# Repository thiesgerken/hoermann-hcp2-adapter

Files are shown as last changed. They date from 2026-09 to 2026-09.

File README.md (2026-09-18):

<div align="center">

# Hörmann HCP2 Adapter

**An open carrier PCB and 3D-printable enclosure for connecting an ESP32-C3 to a Hörmann Series 4 garage door opener.**






</div>

<p align="center">
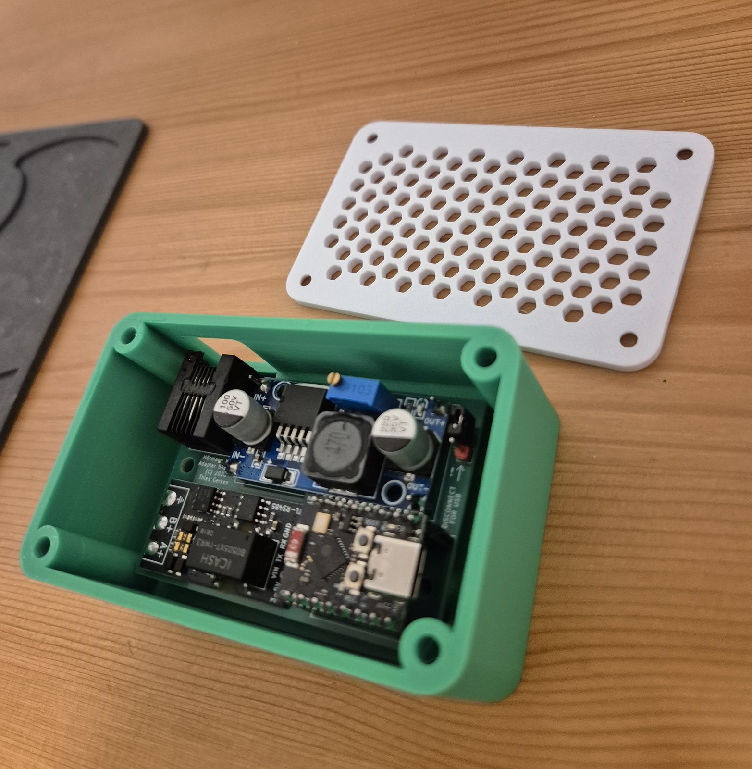
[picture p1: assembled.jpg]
The assembled adapter in its printed tray, with the ventilated lid beside it
  
</p>

<table>
<tr>
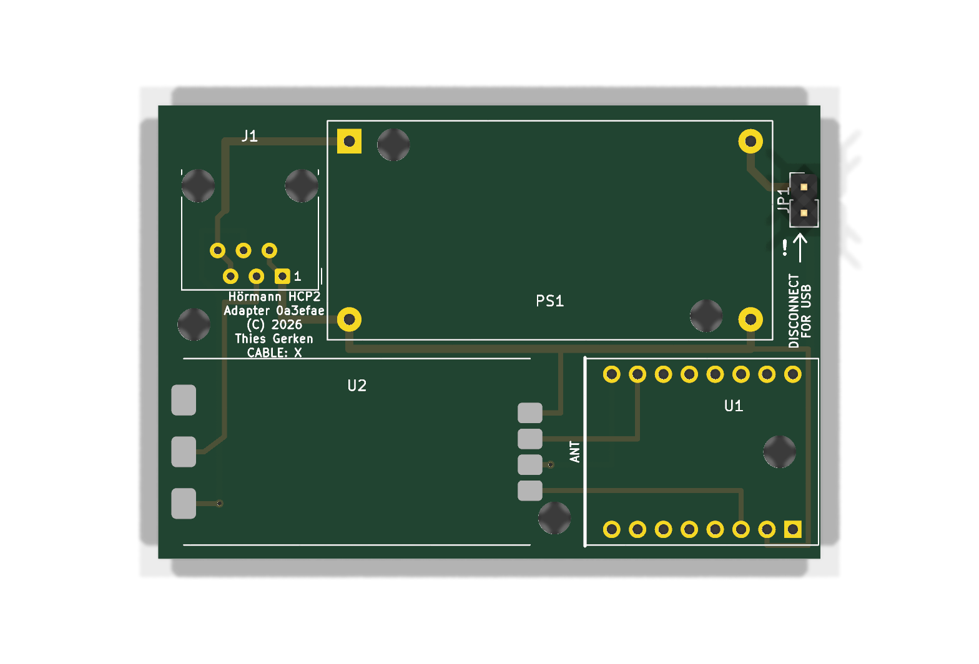
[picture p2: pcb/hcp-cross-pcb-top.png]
Top view of the Hörmann HCP2 adapter PCB
<td width="34%" align="center"><br><strong>65 × 44.5 mm carrier PCB</strong></td>
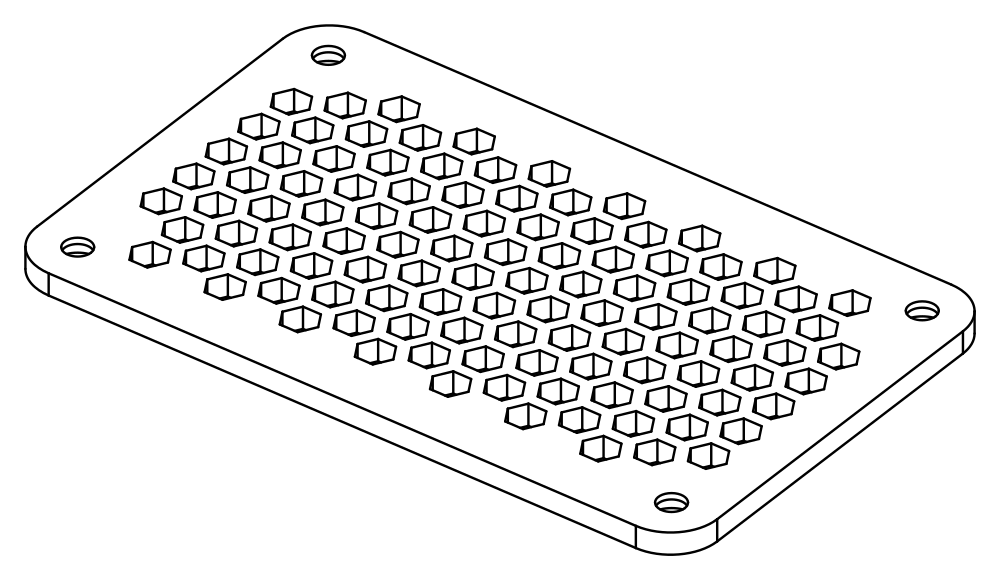
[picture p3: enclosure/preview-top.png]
Enclosure lid CAD preview
<td width="33%" align="center"><br><strong>Ventilated lid</strong></td>
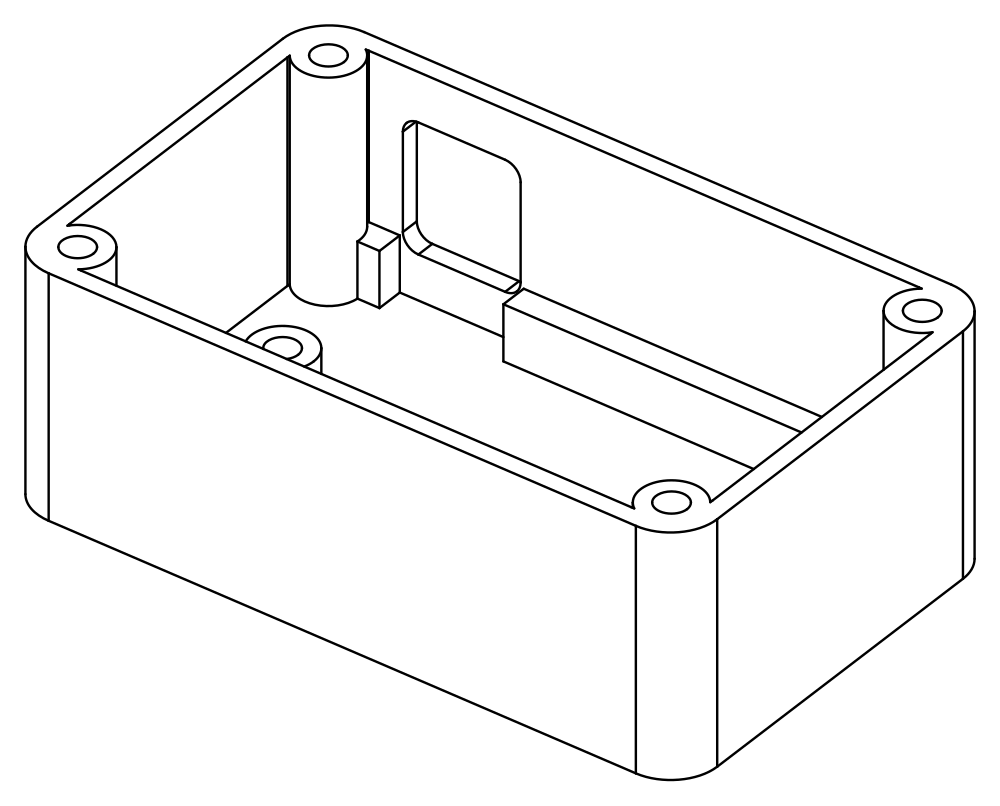
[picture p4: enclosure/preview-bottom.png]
Enclosure tray CAD preview
<td width="33%" align="center"><br><strong>Fitted electronics tray</strong></td>
</tr>
</table>

> [!CAUTION]
> Verify the pinout of your own opener and every conductor of your cable before connecting anything. See [Variants](#variants).
>
> Use this project entirely at your own risk. I am not responsible for any damage, injury, loss, or other consequence resulting from its use in any way. This independent project is not affiliated with, endorsed by, or sponsored by Hörmann.

This is the documentation repository for how I built my adapter around the [ESPHome Hörmann HCP component](https://esphome.io/components/cover/hoermann_hcp/). It may be useful for other people building one as well.

It includes:

- 🧩 a fully routed two-layer KiCad carrier PCB with project-specific footprints
- ⚙️ reproducible Python generators for the schematic, PCB, manufacturing outputs, and renders
- 📦 a compact, parametric build123d enclosure matched directly to the PCB geometry
- 🔌 a ready-to-flash ESPHome configuration with Wi-Fi provisioning
- 🖨️ printable STL files and 3MF assembly previews
- 📚 documented mechanical, electrical, and sourcing decisions

## BOM

### Electronics

| Qty. | Ref. | Component | Notes |
|---:|---|---|---|
| 1 | PCB | Carrier PCB | Two-layer, 65 × 44.5 mm; fabrication files are in [`pcb/`](pcb/) |
| 1 | U1 | [ESP32-C3 Super Mini](reference/docs/purchased-modules.md#esp32-c3-super-mini) | Socketed; runs ESPHome |
| 1 | PS1 | [LM2596 HW-411 buck converter](reference/docs/purchased-modules.md#lm2596-buck-converter-module) | Adjustable; set and verify 5.0 V before connecting U1 |
| 1 | U2 | [Isolated TTL-to-RS485 module](reference/docs/purchased-modules.md#isolated-ttl-to-rs485-module) | 3.3 V/5 V, automatic direction control, integrated 120 Ω termination |
| 1 | J1 | [Unshielded right-angle 6P6C jack](reference/docs/connector-rj12.md) | AliExpress item `1005003078110991`, option `6P6C` |
| 1 | JP1 | 1×2, 2.54 mm pin header and jumper shunt | Disconnects `BUS_PWR` before USB is connected |
| 2 | U1 sockets | 1×8, 2.54 mm socket headers | Keep U1 removable and provide clearance above H4 |
| 1 | W1 | [6P6C cable](reference/docs/purchased-modules.md#6p6c-cable) | Reversed for the `cross` board, straight-through for `straight`. See [Variants](#variants). Verify all six conductors before use |

### Enclosure

| Qty. | Component | Notes |
|---:|---|---|
| 1 | Printed `bottom.stl` | Tray with PCB supports and 6P6C opening |
| 1 | Printed `top.stl` | Ventilated lid |
| 7 | Ruthex M3 heat-set inserts, 5.7 mm long, Ø4.0 mm hole | Four for the lid columns and three for the PCB bosses |
| 4 | M3 × 6 socket cap screws | Lid. Anything longer than 7.5 mm bottoms out in the blind hole |
| 3 | M3 × 6 socket cap screws | PCB. Full thread engagement would need 7.3 mm, and 4.4 mm is ample for M3 |

The LM2596 is not galvanically isolated. The complete adapter therefore shares the HCP supply ground even though the RS485 signal path is isolated. Full galvanic isolation would require an isolated DC/DC converter.

## 🧩 PCB

The [`pcb/`](pcb/) directory is the electrical source of truth. It contains the shared net model, schematic and layout generators, custom footprints, generated KiCad projects, renders, ERC and DRC reports, and fabrication files.

| Property | Value |
|---|---|
| Board | 2 layers, 65 × 44.5 mm |
| Routing | 0.5 mm signals, 0.8 mm power, two vias, three on the straight variant |
| Input | Hörmann HCP2 through a 6P6C jack |
| Controller | Socketed ESP32-C3 Super Mini |
| Power | LM2596 module, approximately 25 V to 5 V |
| Bus interface | Isolated automatic-direction TTL-to-RS485 module |
| Mounting | Three M3 board holes plus one supported corner |

### Variants

Two boards are generated from the same sources. They are identical except for how the six
contacts of J1 map onto the nets, and each one says on its silkscreen which cable it wants.

| Variant | Silkscreen | Cable | J1 contacts |
|---|---|---|---|
| `cross` | `CABLE: X` | Reversed (rollover) | 1, 2 GND · 3 B- · 4 A+ · 5, 6 +25 V |
| `straight` | `CABLE: II` | Straight-through 1:1 | 1, 2 +25 V · 3 A+ · 4 B- · 5, 6 GND |

`cross` follows the pinout in the ESPHome documentation and is the board built and tested
here. The openers measured for this project are mirrored against that pinout, which is why
it needs a reversed cable. `straight` exists for anyone who would rather buy an ordinary
1:1 cable, and for openers that turn out to match it directly.

Measure your own opener before ordering either board. Getting this wrong puts +25 V on the
adapter's ground.

### Layout

| Reference | Part and placement |
|---|---|
| J1 | Amphenol 54601-compatible right-angle 6P6C jack, flush with the top board edge |
| PS1 | 43.4 × 21.2 mm LM2596 HW-411 module, input side toward J1 |
| U2 | 34 × 18 mm isolated RS485 module on castellated pads |
| U1 | ESP32-C3 Super Mini, USB-C flush with the right edge and antenna facing U2 |
| JP1 | `BUS_PWR` disconnect jumper for safe USB use |
| H1, H3, H4 | 3.2 mm M3 mounting holes aligned with the enclosure bosses |

### Generate the design

KiCad must be installed and `kicad-cli` must be available.

```sh
for variant in cross straight; do
  uv run python pcb/schematic.py $variant
  uv run python pcb/pcb.py $variant
done
```

The generators write editable KiCad files directly to [`pcb/`](pcb/), run ERC and DRC, render the schematic and both board sides, and package Gerber and Excellon data. Omitting the argument builds `cross`.

Useful outputs, per variant:

| | Reversed cable | Straight cable |
|---|---|---|
| Editable schematic | [`hcp-cross.kicad_sch`](pcb/hcp-cross.kicad_sch) | [`hcp-straight.kicad_sch`](pcb/hcp-straight.kicad_sch) |
| Schematic PDF | [`hcp-cross-schematic.pdf`](pcb/hcp-cross-schematic.pdf) | [`hcp-straight-schematic.pdf`](pcb/hcp-straight-schematic.pdf) |
| Editable PCB | [`hcp-cross.kicad_pcb`](pcb/hcp-cross.kicad_pcb) | [`hcp-straight.kicad_pcb`](pcb/hcp-straight.kicad_pcb) |
| Layer PDF | [`hcp-cross-pcb.pdf`](pcb/hcp-cross-pcb.pdf) | [`hcp-straight-pcb.pdf`](pcb/hcp-straight-pcb.pdf) |
| Gerber and drill archive | [`hcp-cross-gerbers.zip`](pcb/hcp-cross-gerbers.zip) | [`hcp-straight-gerbers.zip`](pcb/hcp-straight-gerbers.zip) |

The title blocks include the short Git hash of `HEAD`. For release artifacts, commit the sources first, regenerate all four designs, then commit the generated outputs.

## 📦 Enclosure

The [`enclosure/`](enclosure/) directory contains a two-part indoor enclosure generated with [build123d](https://build123d.readthedocs.io/):

- `bottom.stl`: tray with three PCB bosses, a support rail, corner columns, and the 6P6C opening
- `top.stl`: screw-fastened lid with a hexagonal ventilation pattern
- `preview.stl`: open assembly for any STL viewer
- `preview.3mf`: colored assembly with lid and internal hardware

The outer size is **87.8 × 54.3 × 34.0 mm**. Four M3 screws secure the lid into Ruthex threaded inserts. The enclosure is intended for an indoor garage wall and is not waterproof.

PCB dimensions, hole positions, and module placement are imported from [`pcb/pcb.py`](pcb/pcb.py) and the KiCad footprints. Only vertical dimensions and simplified component bodies are maintained separately.

```sh
uv sync
uv run python enclosure/case.py
uv run python enclosure/case.py --show
uv run python enclosure/case.py --png
uv run python enclosure/test_case.py
```

See the [enclosure documentation](enclosure/README.md) for print orientation, clearances, viewer setup, and the mechanical decisions behind the model.

## Assembly notes

Before soldering PS1 onto the carrier board:

1. Power the loose LM2596 module from approximately 25 V with no ESP32 connected.
2. Adjust its output to 5.0 V using the `103` trimmer.
3. Check startup and shutdown behavior under load. The output must not overshoot beyond 5.5 V.
4. Solder PS1 only after those checks pass. Keep `BUS_PWR` open until the remaining board is assembled.

U1 plugs into two 1×8 socket headers. Install the headers, fasten the PCB inside the enclosure, then insert the ESP32. Never connect USB while `BUS_PWR` links the externally supplied 5 V rail.

## HCP2 interface

The ESPHome documentation specifies this pinout for supported Hörmann Series 4 openers:

| Pin | Signal |
|---:|---|
| 1 | GND |
| 2 | GND |
| 3 | B- |
| 4 | A+ |
| 5 | +25 V |
| 6 | +25 V |

The opener's own jack is mirrored against that table: on the ProMatic 4 measured here,
+25 V sits on contacts 1 and 2. The `cross` board follows the table and therefore needs a
**reversed (rollover) cable**, the kind whose two plugs show opposite conductor order when
held identically. The `straight` board mirrors J1 instead and takes a plain 1:1 cable. See
[Variants](#variants).

Measure your opener and every conductor of your cable before the first connection. Pairing
the wrong cable with either board feeds +25 V into the adapter's ground. Doing that here
survived only because the opener limits accessory current to 350 mA.

UART settings: **57600 baud, 8 data bits, even parity, 1 stop bit**. ESPHome participates as a Modbus server. The configuration is in [`esphome/`](esphome/README.md) and uses `GPIO20` for TX and `GPIO21` for RX. That looks reversed next to the net
names on the board, and it is not: U2's TTL pads carry the module's own pin names, so
its `TX` pad drives the ESP32 rather than being driven by it.

## Troubleshooting

The bus offers a hostile debugging environment: it carries power only during a bus scan,
and the opener cuts it again within seconds when the adapter fails to register. That is
too short to read a log. These checks all work on the bench instead, with the board on a
25 V supply and the bus disconnected.

**Does the transmitter work?** Send continuously and measure the DC average, which a plain
multimeter resolves. A temporary `interval` writing 128 zero bytes every 30 ms keeps the
line low about 80 % of the time. Measure between U2's A and B pads:

| A against B | Meaning |
|---|---|
| about 185 mV, unchanged while sending | The driver never switches on. Check the pin roles first |
| moves to roughly 1.6 V while sending | Transmit path is good |
| exactly 0.000 V | The isolated side is not running. The module is dead or unpowered |

The 185 mV is the module's fail-safe bias, so seeing it at all proves the isolated side
has power.

**Does the receiver work?** With the bus disconnected, GPIO21 must sit at a steady 3.3 V.
That is U2's receiver output holding the UART idle level. A wandering level below 0.5 V
means the receiver output is not driving, or the castellated joint is cold.

**Is anything arriving from the bus?** Count bytes instead of logging them. A `uart:`
`debug:` block with a custom `sequence` replaces the default hex dump, so it costs no log
traffic, and a global written to flash with `global_preferences->sync()` survives the
supply being cut. Drive the onboard LED from it and the answer is readable in the garage
without a host attached. Set `dummy_receiver: true` while measuring so the counter does
not depend on Modbus draining the UART, and back to `false` for normal operation.

**Verify the counter before trusting it.** Point the UART at two free neighbouring pins,
GPIO4 and GPIO3, and bridge them. Crosstalk from the transmitting pin is enough to make
the counter run even without the bridge.

## ⚠️ Safety and operating constraints

- Scope is limited to supported Hörmann Series 4 HCP2 devices.
- Disconnect mains power and any emergency battery before installation.
- HCP2 accessories must not be connected or removed while powered.
- Interrupted communication or an ESPHome restart can temporarily block the opener. Power-cycling the opener clears this condition.
- The bus provides approximately 25 V only during a bus scan. The adapter must boot and respond in time.
- Verify the actual jack contact order and every conductor of the cable before first connection, and check that the cable matches the variant printed on the board.
- The selected RS485 module reportedly includes 120 Ω termination. Measure A-to-B resistance with power removed before use. Do not fit a second termination.
- Hörmann specifies a combined 350 mA accessory limit. Measure adapter startup and operating current.

## Repository map

```text
assembled.jpg        Photo of the assembled adapter
LICENSE              MIT, except for the archived third-party material
pcb/                 PCB, schematic, footprints, and fabrication outputs
enclosure/           Parametric enclosure source and printable files
esphome/             ESPHome configuration for the ESP32-C3
reference/docs/      Design records, component notes, and source analysis
reference/           Archived vendor pages, manuals, and datasheets
TODO.md              Open checks, currently none
```

Reference material is intentionally separated from the project deliverables. Start with [`pcb/`](pcb/), [`enclosure/`](enclosure/), and [`esphome/`](esphome/); use [`reference/docs/`](reference/docs/) when a design decision or source needs review.

## License

[MIT](LICENSE), covering the PCB, the enclosure, the generators, the ESPHome
configuration, and the documentation.

[`reference/`](reference/README.md) is excluded. It archives manuals, datasheets, and
vendor listings that belong to their respective owners, with the exception of
[`reference/docs/`](reference/docs/), which is mine and follows the license above.

## Documentation

- [Enclosure design](enclosure/README.md)
- [Firmware](esphome/README.md)
- [Open checks](TODO.md)
- [Components and sourcing status](reference/docs/components.md)
- [Purchased modules](reference/docs/purchased-modules.md)
- [Selected 6P6C jack](reference/docs/connector-rj12.md)
- [Hörmann manual analysis](reference/docs/hoermann-manuals.md)
- [Sources and references](reference/docs/references.md)
- [Decision log](reference/docs/decisions.md)
- [Local vendor archive](reference/README.md)

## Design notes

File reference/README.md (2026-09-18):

# Local source archive

Vendor pages were retrieved on 2026-09-05.

## Copyright

Everything in this directory except [`docs/`](docs/) is third-party material, archived so
that the design decisions in this repository stay verifiable. None of it is my work, none
of it is covered by the repository's MIT license, and no permission to redistribute it is
granted or implied. Rights remain with the respective owners.

| Material | Rights holder |
|---|---|
| [`manuals/`](manuals/) | Hörmann KG. ProMatic 4 opener and accessory documentation. |
| `datasheets/lm2596-ti-snvs124g.pdf` | Texas Instruments |
| `datasheets/esp32-c3-espressif-v2.4.pdf` | Espressif Systems |
| `datasheets/esp32-c3-supermini-community.pdf` | Unattributed vendor document circulating with the board |
| `aliexpress-*/` | The respective sellers and manufacturers. Listing text and images. |
| `esphome-hoermann-hcp-wiring.svg` | The ESPHome project. Taken from its documentation, which is licensed CC BY-NC-SA 4.0. |

[`docs/`](docs/) holds my own design records, component notes, and source analysis, and
follows the repository's [MIT license](../LICENSE).

If you hold rights to any of this material and want it removed, get in touch and I will
take it down.

## Archive contents

| Item | Archived content | Details |
|---|---|---|
| 6P6C cable | Product description, rendered and raw pages, gallery | [`aliexpress-1005005913976427/README.md`](aliexpress-1005005913976427/README.md) |
| 120 Ω resistor | Product description, rendered and raw pages, gallery | [`aliexpress-1005007375826162/README.md`](aliexpress-1005007375826162/README.md) |
| Isolated TTL-to-RS485 module | Product description, rendered and raw pages, gallery | [`aliexpress-1005010178764203/README.md`](aliexpress-1005010178764203/README.md) |
| LM2596 module | Product description, rendered and raw pages, gallery | [`aliexpress-1005006362601789/README.md`](aliexpress-1005006362601789/README.md) |
| ESP32-C3 Super Mini | Product description, rendered and raw pages, gallery | [`aliexpress-1005005967641936/README.md`](aliexpress-1005005967641936/README.md) |
| Selected 6P6C jack | Product description, product pages, gallery, labeled SKU images | [`aliexpress-1005003078110991/README.md`](aliexpress-1005003078110991/README.md) |

`product-description.txt` contains readable text extracted from the rendered product page. `product-page-rendered.html` preserves the generated DOM at retrieval time. `product-page-raw.html`, or `product-page.html` where present, is the raw server response. Gallery images may show different physical variants when a listing offers multiple options.

Vendor claims are not manufacturer datasheets. Footprints, pinouts, and electrical limits must be based on measurements of the delivered sample or applicable manufacturer documentation.

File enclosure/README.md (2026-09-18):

# 📦 Parametric enclosure

A compact 3D-printable enclosure for the carrier PCB in [`../pcb/`](../pcb/).
The model is fully parametric Python built with [build123d](https://build123d.readthedocs.io).

<table>
<tr>
<td width="50%" align="center">Enclosure lid CAD preview<br><strong>Ventilated screw-fastened lid</strong></td>
<td width="50%" align="center">Enclosure tray CAD preview<br><strong>Tray with PCB supports and connector opening</strong></td>
</tr>
</table>

The enclosure has two parts: `bottom.stl`, the tray, and `top.stl`, the lid with a hexagonal ventilation pattern. Four M3 screws fasten the lid into Ruthex threaded inserts in the corner columns. The PCB sits on three bosses below H1, H3, and H4, while a rail supports the remaining corner near the jack. There is no gasket because the enclosure is not waterproof.

**Outer size:** 87.8 × 54.3 × 34.0 mm  
**Inner size:** 83 × 49.5 × 28.8 mm

`case.py` reads the board dimensions, hole pattern, and module locations directly from [`../pcb/pcb.py`](../pcb/pcb.py) and the footprints in `../pcb/HCP.pretty/`. Only component heights and simplified module bodies are maintained manually.

> [!NOTE]
> The module heights in the parameter block come from vendor data. They were checked
> against the assembled board and the printed tray and needed no correction, but they stay
> worth a look if a module is sourced elsewhere.

## Workflow

```sh
uv sync                              # install build123d and ocp-vscode once
uv run python enclosure/case.py       # write the STL and 3MF files
uv run python enclosure/case.py --show
uv run python enclosure/case.py --png
uv run python enclosure/test_case.py  # verify clearances and fit constraints
```

Every run prints the bounding box and volume of both parts. Outputs are written beside the script:

- `bottom.stl` and `top.stl`: print-ready parts
- `preview.stl`: tray, PCB, modules, and plug for generic STL viewers
- `preview.3mf`: named and colored assembly including the lid, with transparency where supported

### Live viewer

Start the viewer in a separate terminal and leave it running:

```sh
uv run python -m ocp_vscode
```

Open <http://127.0.0.1:3939/viewer>, or use the OCP CAD Viewer extension in VS Code. Each `--show` invocation replaces the model while preserving the camera position. Hide the lid in the object tree to inspect the PCB, module envelopes, solder joints, mounting hardware, and inserted 6P6C plug.

The `--png` option renders isometric line drawings without hidden edges. It requires `rsvg-convert`, available on macOS through `brew install librsvg`.

## Layout

Top view with +Y upward. The PCB orientation matches the KiCad render. J1 faces the +Y wall and the U1 USB-C connector faces +X without an external opening.

```text
          ╡ 6P6C ╞
   ┌─────────────────────────────┐
   │ o                         o │   o = corner column with M3 insert
   │   [J1] [   PS1 LM2596   ]JP1│
   │   [ U2 RS485 ] [U1 ESP32-C3]│
   │ o                         o │
   └─────────────────────────────┘
```

## Dimensions

| Feature | Dimension or constraint |
|---|---|
| Walls and floor | 2.4 mm, equal to six 0.4 mm extrusion widths |
| Lid | 2.8 mm |
| PCB | 65 × 44.5 × 1.6 mm, Ø3.2 mm holes from `pcb.py` |
| PCB bosses | 3 × Ø8 × 7.2 mm below H1, H3, H4; Ø4.0 × 6.7 mm blind holes for Ruthex M3 inserts; 1 mm foot fillet |
| Support rail | Along the +Y wall between columns, interrupted at the jack; 3.5 mm deep and 1.5 mm below the PCB edge |
| PCB clearance | 9 mm at ±X, 2 mm toward the jack at +Y, 3 mm at -Y |
| Height above PCB | 16 mm reserved, plus 4 mm lid clearance |
| Jack J1 | 13.2 × 18 mm from the footprint, 11.65 mm high per vendor drawing, latch toward PCB |
| Plug opening | 15.2 × 16.65 mm, 2 mm corner radius, from 3 mm below to 2 mm above the jack |
| Ventilation | 4 mm hexagons across flats, 1.6 mm webs, 2 mm margin from wall rim and screw recesses |
| Lid screws | 4 × M3, Ø3.4 mm clearance, Ø6 × 2 mm counterbore |
| Fasteners | 7 × Ruthex M3 inserts, 5.7 mm long; 7 × M3 × 6 socket cap screws |

## Mechanical decisions

### 9 mm side clearance

The clearance accommodates the corner columns. Components occupy all four PCB corners, so each column must sit beside the board instead of above it. A narrower enclosure would require moving the lid screws or reducing `column_reach` through a smaller `corner_radius`.

### 2.4 mm walls

This small indoor enclosure does not need the 3.2 mm walls used for larger sealed outdoor boxes. Commercial small enclosures commonly use 2 to 2.5 mm walls. The columns overlap 2 mm into the wall and remain within the outer profile.

### One external opening

USB-C remains inside. Remove the lid for flashing and disconnect `BUS_PWR` before connecting USB. JP1 is internal as well. An external USB cutout can be added in `build_bottom()` if operational access becomes necessary.

### Three bosses and one support rail

The PCB has three suitable mounting holes. There is no room for an Ø8 mm boss near the PS1 pads in the fourth corner, so that corner rests on the +Y support rail. Boss faces must remain clear of solder joints. `test_case.py` derives the required boss clearance from every footprint pad using boss radius, pad radius, and a 0.25 mm margin.

### Opening extends below the PCB

The jack latch faces the PCB. The plug lever therefore passes below the plug body and needs clearance beneath the jack face. The support rail is interrupted at the opening, while nearby boss H1 supports the PCB edge.

### 7.2 mm bosses

The Ruthex insert length determines boss height, not the 2 mm solder-joint clearance. The blind hole must remain inside the boss because the floor is too thin to receive the insert.

### 1 mm boss fillet

The bosses sit close to walls, the support rail, and corner columns. A 1 mm fillet avoids collisions. `test_case.py` checks every fillet envelope.

### Lid-only ventilation

Warm air rises, while solid tray walls retain stiffness. The hex grid is clipped to the internal opening so the lid bears continuously on the wall rim and leaves sufficient material around screw recesses.

## Print settings

Wall and web thicknesses are multiples of the 0.4 mm extrusion width and every Z dimension is a multiple of 0.2 mm, so a slicer on that grid fills them with whole extrusions instead of infill.

| Setting | Value | Reason |
|---|---|---|
| Layer height | 0.2 mm | no feature needs finer resolution |
| Wall loops | 3 | 1.2 mm per side fills the 2.4 mm wall and the 2.0 mm ring around each insert completely |
| Extrusion width | 0.4 mm | profiles using 0.42 or 0.45 mm turn the 0.4 mm grid into gap fill |
| Top / bottom layers | 5 / 4 | the 2.4 mm floor is twelve layers |
| Infill | 20 to 25 %, gyroid | carries only the floor and the column cores |
| Supports | optional, tray only | the 15.2 mm plug opening bridges; support there breaks away easily |
| Brim | lid only | a 2.8 mm perforated plate lifts at the corners |
| Hole compensation | none | inserts want tight blind holes, and M3 passes a Ø3.4 hole printed undersize |

PETG is preferred over PLA. It holds screw torque at the threaded inserts better and tolerates a warm garage, although either material works indoors.

The tray prints floor down as exported. Rotate the lid 180° so the screw counterbores face up, which removes the only overhang in that part.

## Before the final print

- Measure the installed heights of the LM2596 including capacitors, the socketed ESP32 including USB-C, and jack J1. Compare the largest value plus clearance with `parts_height`.
- Verify the physical jack height against the 11.65 mm drawing value in `jack_height`.
- Trial-fit a 6P6C plug. The 18 mm deep jack leaves little plug body outside the wall. Confirm that the latch remains reachable through the opening extension below the jack.
- Check the unsupported upper-right PCB corner for play after assembly. It rests only on the support rail.

## Files

```text
case.py        Parametric model and user-facing dimensions
outputs.py     STL, 3MF, PNG, and live-view exports
test_case.py   Clearance and simplified assembly checks
bottom.stl     Print-ready tray
top.stl        Print-ready lid, exterior face down; flip it for printing
preview.stl    Open assembly for viewing only
preview.3mf    Colored complete assembly for viewing only
```

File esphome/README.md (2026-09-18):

# Firmware

ESPHome configuration for the adapter, built around the
[Hörmann HCP component](https://esphome.io/components/cover/hoermann_hcp/).

[`hcp.yaml`](hcp.yaml) exposes the door as a cover, the opener light, the vent and
half-open buttons, and a diagnostic sensor for the bus connection. Wi-Fi credentials,
the API key, and the OTA password live in `secrets.yaml`, which is not committed.

## Setup

```sh
cp esphome/secrets.yaml.example esphome/secrets.yaml   # then fill it in
uvx esphome run esphome/hcp.yaml
```

The first flash needs USB. Hold `BOOT`, press and release `RST`, then release `BOOT` to
enter download mode. Disconnect `JP1` while USB is plugged in, because the LM2596 and USB
would otherwise drive the 5 V rail at the same time.

## Provisioning

Credentials can be set three ways, in the order they become available:

1. `improv_serial` over USB, from the browser-based ESPHome installer or the dashboard.
2. The values in `secrets.yaml`, compiled into the firmware.
3. The `Garage Door Setup` access point plus captive portal, which appears 90 s after
   Wi-Fi fails. This is the only path that works with the enclosure closed.

Bluetooth provisioning (`esp32_improv`) is present but commented out. The BLE stack costs
RAM on the ESP32-C3, and the enclosure exposes no button for an authorizer.

## Pins and bus settings

| Setting | Value |
|---|---|
| UART TX | `GPIO20` |
| UART RX | `GPIO21` |
| Baud rate | 57600, 8 data bits, even parity, 1 stop bit |
| Modbus role | Server, address 2 |

`GPIO20` and `GPIO21` are UART0 on the ESP32-C3, so the logger is pinned to
`USB_SERIAL_JTAG`. Leaving it on UART0 would push log output onto the RS485 bus.

The pin assignment looks swapped against the carrier board's net names because U2
labels its TTL pads from its own point of view: its `TX` pad is an output that drives
the ESP32. Measured on the assembled board, `GPIO20` as TX is the combination that
makes the RS485 driver switch on.

> [!CAUTION]
> Every restart drops the Modbus link and leaves the opener unresponsive to all controls,
> including its own wall button, until the opener is power-cycled. This applies to OTA
> updates. Because of that, `reboot_timeout` is `0s` for both the API and Wi-Fi, so the
> device never reboots itself over a lost connection.

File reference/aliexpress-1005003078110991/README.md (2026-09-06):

# 6P6C HCP jack

Original listing: <https://www.aliexpress.com/item/1005003078110991.html>

AliExpress item `1005003078110991` offers right-angle through-hole modular jacks in several 95001-style contact variants. This project selects only the **unshielded 6P6C** variant with SKU `14-200004891`. The 4P4C, 6P4C, shielded 6P6C, and 8P8C options from the same listing are not used.

## Project use

J1 connects the carrier PCB to the Hörmann HCP2 bus. The electrical assignment is GND, GND, B-, A+, +25 V, +25 V. Confirm contact order, plastic pegs, and hole pattern on the delivered part.

## Archive contents

- `product-description.txt`: readable page text with source URL and retrieval date
- `product-page-raw.html` and `product-page-rendered.html`: raw and rendered product pages
- `sku-options.txt` and `sku-*.avif`: mapping of offered variants
- `gallery-*.webp` and `variant-*.webp`: vendor images of different form factors
- `drawing-6p6c.webp`: mechanical drawing for the selected 6P6C geometry
- `drawing-8p8c-variant.png`: drawing for an 8P8C variant, not valid evidence for the selected jack

Archived on 2026-09-05. Vendor images and dimensions do not replace measurement of the delivered component.

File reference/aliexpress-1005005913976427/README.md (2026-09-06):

# 6P6C patch cable

Original listing: <https://www.aliexpress.com/item/1005005913976427.html>

AliExpress item `1005005913976427` describes an RJ11/RJ12 cable with two 6P6C plugs. Listed lengths were 0.5 m, 1 m, 2 m, 3 m, and 5 m. The vendor describes the wiring as straight-through. The purchased length is not yet recorded.

## Project use

The cable connects the adapter to the HCP2 opener. Before use, verify that both plugs have six contacts, pins 1 through 6 have straight-through continuity, and no contacts are shorted. A crossed telephone cable could swap +25 V and GND.

## Archive contents

- `product-description.txt`: readable page text with source URL and retrieval date
- `product-page-raw.html` and `product-page-rendered.html`: raw and rendered product pages
- `gallery-01.webp` through `gallery-06.webp`: archived vendor images
- `rendered-image-urls.txt`: image sources from the rendered page

Archived on 2026-09-05. The vendor's straight-through claim is not an electrical acceptance test.

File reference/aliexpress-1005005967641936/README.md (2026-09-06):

# ESP32-C3 Super Mini

Original listing: <https://www.aliexpress.com/item/1005005967641936.html>

AliExpress item `1005005967641936` sells a TENSTAR ROBOT ESP32-C3 Super Mini development board with Wi-Fi, Bluetooth, and USB-C. The project board has 16 pins in two rows at 2.54 mm pitch. The common reference form factor measures approximately 22.52 × 18 mm.

## Project use

U1 runs ESPHome. GPIO21 is assigned to UART TX and GPIO20 to UART RX. The board receives 5 V through its pin and provisionally powers the RS485 module from 3.3 V. External 5 V and USB must not be connected simultaneously, so the PCB includes the `BUS_PWR` jumper.

## Archive contents

- `product-description.txt`: readable page text with source URL and retrieval date
- `product-page-raw.html` and `product-page-rendered.html`: raw and rendered product pages
- `gallery-01.webp` through `gallery-06.webp`: vendor images of the board
- `rendered-image-urls.txt`: image sources from the rendered page

Archived on 2026-09-05. Clearly erroneous automated vendor claims, such as a 1 V supply specification, are not accepted as technical data.

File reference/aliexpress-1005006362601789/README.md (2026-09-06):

# LM2596 buck converter module

Original listing: <https://www.aliexpress.com/item/1005006362601789.html>

AliExpress item `1005006362601789` describes an adjustable LM2596S buck converter in the HW-411 form factor. The vendor specifies 3.2 to 46 V input, 1.25 to 35 V output, up to 3 A, and up to 92% efficiency. These limits are not accepted as design data without verification.

## Project use

PS1 converts the approximately 25 V HCP2 supply to 5.0 V. The available module measures 43.4 × 21.2 mm, with four corner pads spaced 39.4 × 17.5 mm. Before soldering, adjust the output to 5.0 V without the ESP32 connected and test for overshoot.

## Archive contents

- `product-description.txt`: readable page text with source URL and retrieval date
- `product-page-raw.html` and `product-page-rendered.html`: raw and rendered product pages
- `gallery-01.webp` through `gallery-06.webp`: vendor images of both sides
- `rendered-image-urls.txt`: image sources from the rendered page

Archived on 2026-09-05. The TI regulator datasheet and measurements of the specific module take precedence over vendor claims.

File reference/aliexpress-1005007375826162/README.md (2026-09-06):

# 120 Ω resistor

Original listing: <https://www.aliexpress.com/item/1005007375826162.html>

AliExpress item `1005007375826162` offers packages of 50 axial metal-film resistors in multiple values. The purchased variant is **120 Ω, 1 W, 1%**.

## Project use

This resistor is a loose spare and measurement part. It is not fitted to the carrier PCB and has no footprint. The selected RS485 module reportedly includes 120 Ω termination. Another parallel termination would produce approximately 60 Ω. Measure resistance between A and B on the unpowered module before commissioning instead.

## Archive contents

- `product-description.txt`: readable page text with variant list, source URL, and retrieval date
- `product-page-raw.html` and `product-page-rendered.html`: raw and rendered product pages
- `gallery-01.webp` through `gallery-05.webp`: archived vendor images
- `rendered-image-urls.txt`: image sources from the rendered page

Archived on 2026-09-05. Verify resistance, tolerance, and power rating on the delivered part before any critical use.

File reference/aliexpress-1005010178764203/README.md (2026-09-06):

# Isolated TTL-to-RS485 module

Original listing: <https://www.aliexpress.com/item/1005010178764203.html>

AliExpress item `1005010178764203` describes a galvanically isolated TTL-to-RS485 module for 3.3 V or 5 V with automatic direction control. The vendor claims up to 2 Mbit/s, protection circuitry, and integrated 120 Ω termination. The approximately 34 × 18 mm module has castellated connections and no installed headers.

## Connections and project use

The TTL side is labeled VIN, TX, RX, and GND. The bus side exposes A+, B- or B+ in some images, plus a third earth or unused terminal. U2 connects the ESP32-C3 UART to HCP2 A+ and B-. Leave the third bus terminal open. The planned 3.3 V supply must be verified on the delivered module.

## Archive contents

- `product-description.txt`: readable page text with source URL and retrieval date
- `product-page-raw.html` and `product-page-rendered.html`: raw and rendered product pages
- `gallery-01.webp` through `gallery-06.webp`: vendor images of both sides
- `rendered-image-urls.txt`: image sources from the rendered page

Archived on 2026-09-05. Measure A/B labeling, logic levels, galvanic isolation, and termination resistance on the specific module.

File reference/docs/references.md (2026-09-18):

# Sources and references

Sources are grouped by authority. Vendor claims are not treated as manufacturer datasheets.

## Primary sources

| Topic | Source | Used for |
|---|---|---|
| ESPHome Hörmann HCP | <https://esphome.io/components/cover/hoermann_hcp/> | Supported openers, HCP2 pinout, 25 V supply, 120 Ω termination, BUS scan, and operating warnings |
| ESPHome UART | <https://esphome.io/components/uart/> | 57600 baud, even parity, and one stop bit |
| ESP32-C3 | <https://www.espressif.com/sites/default/files/documentation/esp32-c3_datasheet_en.pdf> | Electrical limits, GPIO functions, strapping pins, and UART |
| LM2596 | <https://www.ti.com/lit/ds/symlink/lm2596.pdf> | IC limits and reference circuit, provided that the purchased module uses the claimed regulator |

Local copies:

- [Espressif ESP32-C3 datasheet](../datasheets/esp32-c3-espressif-v2.4.pdf)
- [Texas Instruments LM2596 datasheet](../datasheets/lm2596-ti-snvs124g.pdf)
- [ESPHome HCP wiring diagram](../esphome-hoermann-hcp-wiring.svg)

## Manuals for the specific opener

| Document | Local copy | Project relevance |
|---|---|---|
| ProMatic 4 installation, operation, and maintenance, 4511178 B0 / 18-2022 / RE | [PDF](../manuals/garagentor_4511178_ProMatic_4_DE.pdf) | BUS activation, BUS scan, safety, and operating instructions |
| ProMatic 4 functional description and accessories, 4553098 B0 / 21-2022 | [PDF](../manuals/garagentor_4553098_B0_ProMatic_4_Funktionsbeschreibung_Zubehoer.pdf) | BUS scan, Series 4 accessories, and 350 mA combined limit |
| HOR1-HCP option relay, TR30A117 / 07.2019 | [PDF](../manuals/garagentor_hoermann-optionsrelais-hor1-hcp-anleitung.pdf) | Series 4, 10 m BUS cable limit, and participant status |

Analysis: [Hörmann manual analysis](hoermann-manuals.md)

## Reference implementations and form-factor sources

| Topic | Source | Limitation |
|---|---|---|
| HCPBridge | <https://github.com/hkiam/HCPBridge> | Protocol and implementation comparison, not a normative hardware specification |
| ESP32-C3 Super Mini | <https://github.com/sigmdel/supermini_esp32c3_sketches> | Community documentation for a common form factor; generic board variants can differ |
| Super Mini community datasheet | [local PDF](../datasheets/esp32-c3-supermini-community.pdf) | Confirm pinout and dimensions on the delivered board |

## Vendor sources

Complete local index: [reference/README.md](../README.md)

| Part | Source | Local archive |
|---|---|---|
| 6P6C cable | <https://www.aliexpress.com/item/1005005913976427.html> | [archive](../aliexpress-1005005913976427/) |
| 120 Ω resistor | <https://www.aliexpress.com/item/1005007375826162.html> | [archive](../aliexpress-1005007375826162/) |
| Isolated TTL-to-RS485 module | <https://www.aliexpress.com/item/1005010178764203.html> | [archive](../aliexpress-1005010178764203/) |
| LM2596 module | <https://www.aliexpress.com/item/1005006362601789.html> | [archive](../aliexpress-1005006362601789/) |
| ESP32-C3 Super Mini | <https://www.aliexpress.com/item/1005005967641936.html> | [archive](../aliexpress-1005005967641936/) |
| Selected 6P6C jack | <https://www.aliexpress.com/item/1005003078110991.html> | [archive](../aliexpress-1005003078110991/) |

## Source rules

- A manufacturer datasheet outranks a vendor drawing.
- A vendor drawing outranks assumptions inferred from product photos.
- Measurements of the delivered part determine the footprint.
- Document discrepancies between sources and measurements instead of silently correcting them.
- Retain the order link, markings, datasheet, pinout, and footprint evidence for every approved module.
- Archive AI-generated vendor summaries, but do not use them as technical sources.

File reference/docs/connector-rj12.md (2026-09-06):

# Selected 6P6C jack

## Selection

J1 uses the **unshielded `6P6C`** option from AliExpress item `1005003078110991`.

Do not order the `4P4C`, `6P4C`, shielded `6P6C`, or `8P8C` variants.

The option image shows six contacts and an unshielded right-angle through-hole jack. The vendor provides neither a reliable manufacturer nor an unambiguous manufacturer part number. Confirm pin 1, hole pattern, and all dimensions on the delivered sample.

## Source

- Vendor: AliExpress
- Item: `1005003078110991`
- Listing title: `10PCS RJ11 Telephone Socket Bent Pin 95001 4P4C 6P6C 6P4C 8P8C Female Jack PCB Connector`
- Selected option: `6P6C`
- Canonical URL: <https://www.aliexpress.com/item/1005003078110991.html>
- Retrieved: 2026-09-05

Local copies:

- [archived product description](../aliexpress-1005003078110991/product-description.txt)
- [rendered product page](../aliexpress-1005003078110991/product-page-rendered.html)
- [labeled SKU list](../aliexpress-1005003078110991/sku-options.txt)
- [selected variant image](../aliexpress-1005003078110991/sku-6p6c-unshielded.avif)
- [8P8C variant drawing](../aliexpress-1005003078110991/drawing-8p8c-variant.png), including pin numbers and PCB layout

The generic gallery mixes multiple variants and is not valid footprint evidence for the selected option.

## Footprint

The board uses `HCP:RJ12_Amphenol_54601-x06_Horizontal`, copied from the KiCad library into [`pcb/HCP.pretty/`](../../pcb/HCP.pretty/). The vendor drawing for the purchased 6P6C jack, labeled `53-6p6c`, matches the Amphenol 54601 geometry:

- 13.2 × 18 mm body
- Ø3.2 mm pegs at 10.16 mm spacing
- pegs 8.89 mm behind the pin rows
- Ø0.9 mm pins staggered by 1.27 mm in rows 2.54 mm apart
- pin rows 14.23 mm and 16.77 mm behind the front face

The front face is flush with the PCB edge. In top view with the board edge at the top, pin 1 is at the right of the rear row. Pin 2 is to its left in the front row, alternating through pin 6 at the front left. The silkscreen marks pin 1.

## Latch-down orientation

Drawings for some 95001-family jacks show the latch slot above the opening, contact springs below, and 1.02 mm pin staggering. The purchased 6P6C is a different geometry: latch slot toward the PCB, springs along the upper wall, and 1.27 mm pin staggering. The latch-down orientation mirrors the top-view contact sequence.

- TIA/FCC reference view: plug latch down, contacts up and facing the viewer, cable toward the viewer, pin 1 at left.
- Looking into a latch-down jack from the front, contact 1 is at left.
- Front and top views reverse left and right. Pin 1 is therefore at the right in PCB top view.
- A latch-up jack would place pin 1 at the left in PCB top view.

The Amphenol 54601 `tab down` footprint uses this numbering. Rotating it 180 degrees places pin 1 at the rear right. This assumes each contact spring connects straight back to its corresponding pin, as shown for this geometry.

Confirm on the sample with a continuity meter: latch slot toward the PCB, contact 1 connected to the rear-right pin in PCB top view.

## HCP2 assignment

The assignment below comes from the ESPHome HCP documentation, not the jack vendor.

| Jack contact | HCP2 signal |
|---:|---|
| 1 | GND |
| 2 | GND |
| 3 | B- |
| 4 | A+ |
| 5 | +25 V |
| 6 | +25 V |

The view into the jack opening is authoritative. Do not infer the sequence from a potentially mirrored solder-side view.

## PCB release criteria

- The delivered variant has six fitted contacts and no shield.
- A 6P6C plug latches mechanically.
- Body width, depth, height, contact locations, and plastic pegs are measured.
- Contact order is measured using an inserted straight-through cable.
- Pin 1 uses the same viewing convention in the KiCad symbol, footprint, schematic, and silkscreen.
- The plug faces the intended direction at the PCB edge.
- The selected cable is verified as straight-through.

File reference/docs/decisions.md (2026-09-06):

# Decision log

| ID | Date | Status | Decision | Rationale or approval condition |
|---|---|---|---|---|
| D-001 | 2026-09-05 | Decided | Do not create a complete schematic or PCB layout yet. Document and measure the purchased parts first. | Module variants and footprints must be verified on delivered samples. |
| D-002 | 2026-09-05 | Decided | The first board is a carrier for ESP32-C3, LM2596, and isolated RS485 modules. | All three modules have already been purchased. Integrating individual ICs would be a different design. |
| D-003 | 2026-09-05 | Decided | J1 is the unshielded `6P6C` option from AliExpress item 1005003078110991. | The selection is fixed. Measure the hole pattern and contact order before releasing the PCB. |
| D-004 | 2026-09-05 | Decided | Do not add a 120 Ω termination resistor or footprint to the carrier PCB. | The selected RS485 module reportedly includes termination. Measure resistance between A and B before commissioning. |
| D-005 | 2026-09-05 | Decided | Do not add protection circuitry at the HCP input. | Reverse polarity is addressed by D-014. The design relies on the Hörmann supply for surge behavior and on the RS485 module for A/B ESD protection. |
| D-006 | 2026-09-05 | Decided | Add a disconnectable `BUS_PWR` link to the 5 V supply from the LM2596. | The Super Mini form-factor documentation prohibits simultaneous USB and external power. |
| D-007 | 2026-09-05 | Decided | Power the RS485 module from the ESP32-C3 Super Mini 3.3 V rail. | This avoids a possible 5 V signal at ESP32 RX. The vendor specifies 3.3 V operation; no separate qualification was requested. |
| D-008 | 2026-09-05 | Observed | The first build is not fully galvanically isolated. | The non-isolated LM2596 connects supply grounds. The RS485 module isolates only the signal path. |
| D-009 | 2026-09-05 | Decided | Generate the first schematic before footprints are finalized. | The electrical topology is known and does not depend on mechanical dimensions. |
| D-010 | 2026-09-05 | Provisionally decided | Generate a fully routed preliminary PCB with clearly identified provisional footprints. | This permits early review of board size, placement, and routing. Release still requires physical measurements. |
| D-011 | 2026-09-05 | Provisionally decided | Use a 65 × 44.5 mm PCB with module-specific footprints. Place J1 at the edge, and use module holes plus a hole below U1 for mounting. | Avoid wasted area. Confirm vendor-derived measurements before fabrication. |
| D-012 | 2026-09-05 | Decided | Generate schematic and PCB directly as KiCad files from `design.py`, without SKiDL. Run ERC, DRC, and netlist operations through `kicad-cli`. | The SKiDL route required regex post-processing for readable layout. Direct generation is shorter and produces a clean schematic. |
| D-013 | 2026-09-05 | Decided | Give J1 a custom `RJ12_95001_6P6C` footprint instead of the Amphenol 54601 footprint. | The initially reviewed 95001-family drawing used different pin and peg spacing. |
| D-014 | 2026-09-05 | Decided | Do not add reverse-polarity protection to the 25 V input. | Reverse polarity is possible only with a crossed telephone cable. Every cable must be verified as straight-through before connection. |
| D-015 | 2026-09-06 | Decided | Restore the Amphenol 54601-compatible footprint for J1, rotated 180 degrees. | The drawing for the purchased 6P6C type `53-6p6c` matches its 13.2 × 18 mm body, Ø3.2 mm pegs at 10.16 mm spacing, 1.27 mm staggered pins, and latch-down orientation. Supersedes D-013. |

Assign each new decision the next sequential ID. Record changed decisions as new entries so the original rationale remains visible.

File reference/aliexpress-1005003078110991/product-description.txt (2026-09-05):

10 Stück RJ11 RJ12 Buchse 4P4C 6P4C 6P6C 8P8C weiblich

Source: https://de.aliexpress.com/item/1005003078110991.html
Archived: 2026-09-05

AliExpress
AliExpress App herunterladen
Other/DE/
EUR
Willkommen
Anmelden / Registrieren
0
Einkaufswagen
10PCS RJ11 Telefon Buchse Gebogene Pin 95001 4P4C 6P6C 6P4C 8P8C Weibliche Jack PCB Stecker
  4.9  
32 Bewertungen
  ౹  
600+ verkauft
2,39€ 
10 Stück,0,24€/Stück ; Preis inkl. MwSt. | Zölle werden an der Kasse berechnet  ; Zusätzlicher 2 % Rabatt
Mit PayPal Zahlung in 30 Tagen ohne Zinsen bezahlen.
Farbe: 4P4C
KI-generierte Artikelübersicht

Haftungsausschluss: Dieser Inhalt wurde mithilfe von KI generiert und spiegelt nicht die Meinung des Verkäufers wider. Die Plattform und die Verkäufer übernehmen hierfür keine rechtliche Haftung.

10 Stück pro Packung – ideal für den professionellen Einsatz Diese 10PCS RJ11 Telefonbuchse ist perfekt für den Einsatz in der Elektronikfertigung oder Reparatur. Die hohe Stückzahl pro Packung sorgt für geringe Kosten pro Einheit und optimale Verfügbarkeit.
Vielseitige Anschlussvarianten – kompatibel mit mehreren Steckertypen Unterstützt 4P4C, 6P4C, 6P6C und 8P8C Anschlüsse. Ideal für Telefon- und Netzwerkkabel mit unterschiedlichen Kontaktkonfigurationen in industriellen und privaten Anwendungen.
Stabile Bauweise mit geschirmter Version verfügbar Die 6P6C mit Shield Version bietet zusätzlichen Schutz gegen elektromagnetische Störungen. Perfekt für sensible Datenübertragung in hochfrequenten Umgebungen.
CE-zertifiziert – Sicherheit und Qualität garantiert Alle Stecker sind CE-zertifiziert und entsprechen den europäischen Sicherheitsstandards. Garantiert sichere Nutzung bei unter 50Vac oder 75Vdc nach EU LVD.
Platzsparende Verpackung – ideal für Lagerung und Transport Die Packung misst 10 x 5 x 5 cm und wiegt nur 30 g. Perfekt für kleine Lagerflächen und einfache Logistik bei Großbestellungen.
Mehr
Weitere Preisinformationen 
Kundenbewertungen (32)
Spezifikationen
Übersicht
Laden
Das könnte Sie auch interessieren
Bewertungen | 4.9
 
 
32 Bewertungen
 
Alle von verifizierten Einkäufen
Alle Bewertungen (4) (2) (0)schnelle lieferung (4)unbeschädigte verpackung (2)empfohlen (2)ästhetik (1)passt richtig (1)funktioniert perfekt (1)
5.0
5.0
4.0
4.0
Mehr anzeigen
Standardmäßig sortierenOriginalsprache anzeigen
Farbe:6P6C
Gekauft für die Verwendung mit meinem intelligenten Stromzähler nach DSMR5-Standard und erfüllt seinen Zweck perfekt.
M***n | 20 Sept. 2025
 Hilfreich (0)   
Farbe:6P6C mit Abschirmung
Alles in Ordnung. Alles ist gut. Das Paket kam schnell an. Die Verpackung ist unbeschädigt. Das Aussehen ist normal. Ich werde später mehr bestellen. Danke.
AliExpress-Einkäufer | 24 Okt. 2025
 Hilfreich (0)   
Farbe:4P4C
Alles wie beschrieben. Schnelle Lieferung. Ich empfehle den Verkäufer.
I***K | 29 Nov. 2025
 Hilfreich (0)   
Mehr anzeigen
Ähnliche Artikel
Previous
YYT 10 Stück RJ11 RJ12 gebogener Stift 95001 4P4C 6P6C 6P4C 8P8C Telefonsteckdose mit Abschirmung 90 Grad
1,59€
5
287 verkauft
1,52€ sparen
10Pcs 6P6C RJ11 RJ12 PCB Mount Telefon Modular Stecker Socket-schnittstelle Kristall Buchse Telefon Für Plug Jack
0,88€
1,29€
-32%
5
321 verkauft
10 Stück RJ11-Buchse RJ12-Telefonbuchse 56-6P6C Buchse mit geschirmtem Kupfergehäuse L = 18,5 mm
4,09€
12 verkauft
Kostenloser Versand ab 10€
5 Stück 180 Grad vertikale RJ45-geschirmte Netzwerksteckdose mit LED – 5224 8P8C Inline-Leiterplattenstecker für Ethernet
2,19€
(0,44€/Stück)
5
175 verkauft
3+, kein Zollaufschlag
3,49€ sparen
Kombi-Knaller
Werbeanzeige
10 Stück RJ11-Buchse 52-6P6C 4P4C 8P8C Sitz RJ12 Telefonbuchse Weiblich Kristallkopf Stecker 180 Grad Vertikal 6P6C Telefonanschluss
1,39€
1,64€
-15%
5
43 verkauft
Next
Spezifikationen
Ist drahtlose Funktionalität enthalten?
Nein
Ist eine Batterie im Lieferumfang enthalten?
Nein
EU LVD-Spannung
Niederspannung: Unter 50 VAC oder 75 VDC
Hochbetriebenes Chemikalienunternehmen
Keine
Modellnummer
RJ11 RJ12
Spannung
Keine
Mehr anzeigen
Artikelanleitungen und Dokumente
Benutzerhandbuch
Anzeigen
Übersicht
Melden
Mehr anzeigen
Informationen zu Zusatzkosten
Bei von außerhalb der Europäischen Union gelieferten Artikeln fallen in Ihrem Land u. U. weitere MwSt.- und wenn anwendbar Zollgebühren an. Wenn AliExpress per Gesetz zur Erhebung der MwSt. verpflichtet ist, wird der Preis an der Kasse inklusive Mehrwertsteuer angezeigt. Für weitere Informationen zu diesen Kosten wenden Sie sich bitte an das Finanzamt bzw. die Zollbehörde Ihres Landes.
Verkauft durch excellence electronic. Logistik durch AliExpress.
Informationen zur Produktkonformität
Haftungsausschluss
Haftungsausschluss: Bilder und Produktinformationen auf dieser Seite können automatisch von KI übersetzt worden sein. Diese Übersetzungen werden nur zur Bequemlichkeit und im Ist-Zustand bereitgestellt und können Ungenauigkeiten oder Inkonsistenzen enthalten.
2,39€ 
10 Stück,0,24€/Stück ; Preis inkl. MwSt. | Zölle werden an der Kasse berechnet  ; Zusätzlicher 2 % Rabatt
Farbe: 4P4C
 
Bearbeiten
Verkauft von
excellence electronic
(Händler)
 Kontaktieren
  
  
AliExpress-Verpflichtung
Pick-up points  
Kostenloser Versand über 10,00€  
Zustellung: Um Sep 12 - 17 
Kurierdienst:   DHL Paket   Hermes ,etc.  
Expresslieferung
 
1,00€ Coupon-Code für die verspätete Lieferung
 
Geld zurück bei defekt geliefertem Artikel
 
Geld zurück bei verlorenem Paket
 
Geld zurück bei Nichtlieferung in 40 Tagen
Rückgabe bis 90 Tage kostenlos
Sicherheit und Datenschutz persönliche Daten schützen
Sichere Zahlungen: Wir geben keine Ihrer personengebundenen Daten ohne Ihre Zustimmung an Dritte weiter.
Persönliche Angaben schützen: Wir schützen Ihre Privatsphäre und bewahren Ihre personengebundenen Daten sicher auf.
Menge
3431 verfügbar
Jetzt kaufenIn den Warenkorb
 Teilen
 140
  
excellence electronic
98.7% Positives Feedback | 9665 Follower
 
Kontaktieren
Empfohlen von excellence electronic
5 Sätze 2edgrk-2,54mm Mikro klemmen block Plug-In 15edgkp 2p/3p/4p/5p/6p/8p Stecker und Buchse Set grüne Schraub klemme
2,79€
(0,56€/Satz)
5
94 verkauft
3+, kein Zollaufschlag
1,06€ sparen
Kombi-Knaller
5PCS PA2.0 Terminal Draht Einzel Doppel Ende mit Schnalle Anschluss Draht 26AWG 10/15/20CM PA 2,0mm Gehäuse Reverse Gleiche Richtung
2,65€
(0,53€/Stück)
5
243 verkauft
Kostenloser Versand ab 10€
Bester Preis in ähnlichen Angeboten
5PCS HR911105A Ethernet Interface RJ45 Netzwerk Transformator 100M Single Port RJ45 Stecker
3,35€
(0,67€/Stück)
5
167 verkauft
Kostenloser Versand ab 10€
10Sets PHD 2,0 MM Zweireihig 2X2/3/4/5/6/7/8/9/10pin PHD 2,0 Stecker Gerade/Gebogene Nadel Stecker Männlich + Weiblich + Crimps
1,86€
(0,19€/Satz)
-5%
4.9
334 verkauft
3+, kein Zollaufschlag
Kombi-Knaller
10PCS PT1.5 Schraubenlose Terminal Block 1,5mm2 Draht Schnell Push-In Din-Schiene Terminal Elektrische Stecker
1,42€
(0,14€/Stück)
4.7
377 verkauft
3+, kein Zollaufschlag
Bester Preis in ähnlichen Angeboten
Kombi-Knaller
5PCS 5,5x2,5 5,5x2,1 4,8x1,7 4,0x1,7 3,5x1,35 3,5x1,1 2,5x0,7mm Männlich DC Power Stecker Stecker Winkel 90 L Geformte Stecker
2,03€
(0,41€/Stück)
5
56 verkauft
3+, kein Zollaufschlag
Kombi-Knaller
Das könnte Sie auch interessieren
10-20Pcs RJ12 6P6C RJ11 PCB Mount Telefon Modulare Stecker Buchse Interface Kristall Buchse Telefon Für Stecker jack
2,65€
(0,26€/Stück)
5
228 verkauft
3+, kein Zollaufschlag
0,02€ sparen
Kombi-Knaller
Werbeanzeige
10-50Pcs RJ12 6P6C RJ11 PCB Mount Telefon Modulare Stecker Buchse Interface Kristall Buchse Telefon Für Stecker jack 55A
2,99€
(0,3€/Stück)
4.6
180 verkauft
3+, kein Zollaufschlag
0,02€ sparen
Kombi-Knaller
Werbeanzeige
10 Stück RJ11 Telefonbuchse 4P4C 6P6C 8P8C Vertikaler Kristallkopf Buchse Schwarz
1,49€
1,59€
-6%
5
151 verkauft
Bester Preis in ähnlichen Angeboten
5PCS RJ45 Netzwerk Ethernet 8P8C Buchse Anschlüsse 8Pin PCB Mount 21MM Einzigen Netzwerk Port
1,69€
(0,34€/Stück)
4.8
489 verkauft
3+, kein Zollaufschlag
0,01€ sparen
Kombi-Knaller
5PCS RJ11 RJ12 RJ45 Telefon WEIBLICHE BUCHSE 4P4C 6P4C 6P6C 8P8C Stecker Mit Draht Weibliche Jack Anschlüsse 616E 623K 641D
3,46€
(0,69€/Stück)
4.6
200 verkauft
3+, kein Zollaufschlag
Kombi-Knaller
50 teile/los schwarz rj45 8 p8c jack anschluss kunststoff pcb mount netzwerk internet modular 18,5mm
8,49€
9,54€
-11%
4.9
157 verkauft
Hängelampen für die Heimdekoration, luxuriöser Kristall-Kronleuchter für das Wohnzimmer, Hängelampe für das Esszimmer, Deckenleuchte, Innenbeleuchtung
107,39€
5
8 verkauft
126,07€ sparen
Kostenloser Versand
Werbeanzeige
1PCS RJ45 Vertikale 5224 8P8C Weibliche Netzwerk buchse Schnittstelle Kristall Kopf Buchse 180 grad Stecker Kunststoff/metall mit licht
0,52€
0,74€
-30%
4.9
388 verkauft
Werbeanzeige
20 Stück RJ9 RJ10 RJ22 4P4C Handset Wire Socket Vert PCB Jack 15 x 11 x 15 mm
10,59€
3 verkauft
Nordic wohnkultur Kronleuchter für esszimmer glanz anhänger lichter hängen lampen für decke Leuchte innen beleuchtung
189,69€
3.7
17 verkauft
155,2€ sparen
Kostenloser Versand
Werbeanzeige
1Pcs RJ45 Adapter Board Zu XH2.54 Modulare Ethernet Stecker Adapter Netzwerk Interface + Breakout Board + Pin Header
1,59€
4.8
2.000+ verkauft
3+, kein Zollaufschlag
0,33€ sparen
Kombi-Knaller
10 stücke RJ45 8P8C Schwarz Computer Internet Netzwerk PCB Jack Buchse
2,15€
5
101 verkauft
Kostenloser Versand ab 10€
TOOLEYE 10-teiliges PCB-Bohrer-Set, Mikrobohrer, Leiterplatte, 1/8 Zoll Schaft, Mini-CNC-Bohrer, 0,1–3,175 mm Bohrwerkzeuge
2,79€
(0,28€/Stück)
4.8
10.000+ verkauft
Auf AliExpress meistverkauft
Kostenloser Versand ab 10€
Werbeanzeige
10Pcs RJ45 Rechten Winkel Ethernet 8P8C Einzigen Netzwerk Port Buchse PCB Solder Anschlüsse Großhandel
2,59€
2,79€
-7%
4.7
309 verkauft
3+, kein Zollaufschlag
Bester Preis in ähnlichen Angeboten
Kombi-Knaller
8 terminal block Single-port netzwerk anschlussdose rj45-netzwerkkabel anschlussdose 8P8C Desktop-box Händler RJ45 CONNECTER
71,39€
89,24€
-20%
5
42 verkauft
Kostenloser Versand
Werbeanzeige
10Pcs GX12 Stecker Mutter Typ 2/3/4/5/6/7 Pin Männlich Weiblich 12mm Rund Luftfahrt Stecker Stecker Panel Mount Buchse Stecker
4,79€
(0,48€/Stück)
5
198 verkauft
3+, kein Zollaufschlag
0,57€ sparen
Kombi-Knaller
Werbeanzeige
5 Stück rj11 rj12 rj45 Telefonbuchse mit Kabel 4 p4c 6 p4c 6 p6c 8 p8c Buchse 616e 623k 641d
3,79€
4,8€
-21%
5
72 verkauft
4P4C 6P4C 6P6C 8P8C RJ11 Telefon Modular Stecker Jack RJ11 Stecker Kristall Kopf Ethernet Kabel Stecker Köpfe
0,98€
(0,1€/Stück)
5
78 verkauft
Kostenloser Versand ab 10€
Effiziente Original Tragbare SSD-Festplatte USB3.1 Typ-C 1TB 4TB 128TB Große Kapazität Externe Solid-State-Festplatte Kompatibel
15,89€
24,45€
-35%
5
1 verkauft
Werbeanzeige
RJ11 6P4C CAT3 Telefon-Keystone-Buchse mit 4-Pin-Schraubklemmen-Anschlussplatine, RJ11-Buchse auf 4-Pin-Schraubanschluss
1,99€
12 verkauft
Kostenloser Versand ab 10€
Bester Preis in ähnlichen Angeboten
Werbeanzeige
Stecker RJ9 4P4C 90-Grad-Sbloccato-Sockel PCB Monto DIP
14,39€
1 verkauft
Kostenloser Versand
Werbeanzeige
Moderne Wohnkultur LED-Leuchten Pendelleuchte Lampen für Treppenhaus Kronleuchter für Wohnzimmer Hängeleuchte Innenbeleuchtung
124,69€
5
7 verkauft
146,38€ sparen
Kostenloser Versand
Werbeanzeige
COMNEN RJ9 -RJ9/RJ11-RJ45 Telefon-Datenkabel 4P4C 6P4C 8P4C Stecker auf Stecker Modulares Datenkabel Handset Sprachverlängerungsdatenkabel
4,39€
5
104 verkauft
2,58€ sparen
5/10 Stück RJ45 8P8C geschirmte Buchse, 8-poliger Netzwerkschnittstellenanschluss mit gelb-grüner LED, einzelner/doppelter RJ45-Anschluss
2,85€
(0,57€/Stück)
7 verkauft
3+, kein Zollaufschlag
2,85€ sparen
Kombi-Knaller
Werbeanzeige
Andere suchten auch
Ähnliche Suche
rj11 steckers maße
rcd steckers whirlpool
rj12 rj11
qc4 steckers
motorrad steckers
rcb r11 scooter
c17 steckers
japanische steckers
gps steckers
ladegerät steckers
wlan router steckers
12v auto steckers
Ranking-Keywords
rj45 steckers
rj45 stecker
rj11
steckverbinder 6 polig
lc apc stecker
rj45 stecker löten
rc11
mini din stecker 6 polig
steckers
deutsch dtm 3 pin connector
4 pin deutsch connector assembly
deutsch 8 pin wire connector
Dieser Artikel gehört zur Home, finden Sie ähnliche Produkte bei Alle Kategorien, Licht & Beleuchtung, Beleuchtungszubehör, Steckverbinder.
Hilfe
Hilfe-Center, Streitigkeiten & Berichte, Rückgabe-und Erstattungsrichtlinie, RGE-Verletzung melden, DSA/OSA-Informationen , Integrität und Konformität , Transparenz zentrum, Beschwerdeeinstieg ohne Anmeldung, Rückerstattungsrichtlinie
Mehrsprachige AliExpress-Websites
Pусский, Portuguese, Spanish, French, German, Italian, Dutch, Turkish, Japanese, Korean, Thai, Arabic, Hebrew, Polish
Browse by Category
Alle beliebten , Produkt , Aktion , Günstiger Preis , Toller Wert , Bewertungen , Wiki, Video
Alibaba Group
Alibaba Group Website, AliExpress, Alimama, Fliggy, Alibaba Cloud, Alibaba International, AliTelecom, DingTalk, Juhuasuan, Taobao Marketplace, Tmall, Taobao Global, AliOS, 1688
Intellectual Property Protection - Privacy Policy - Cookie‑Einstellungen - Sitemap - AliExpress.com Nutzungsbedingungen - Informationen für EU-Verbraucher - Rechtliche Hinweise / Impressum - Transaktionsdienstleistungsvertrag für Verbraucher außerhalb der EU/des Vereinigten Königreichs - Allgemeine Geschäftsbedingungen für EU/EEA/UK-Verbraucher - User Information Legal Enquiry Guide ©️ 2010-2025 AliExpress.com. All rights reserved.
Cookie-Einstellungen
Später
Wir verwenden Cookies und ähnliche Technologien für die Verbesserung des Benutzererlebnisses und die Personalisierung von Werbung.Auf diese Weise können wir und Drittanbieter Ihnen sowohl auf als auch außerhalb unserer Websites Inhalte, Marketing und Werbung anbieten, die Ihnen gefallen könnten. Ihre Einstellungen können Sie jederzeit unter Cookie-Einstellungen“ ändern. Weitere Informationen finden Sie in unserem Cookie-Hinweis.
Cookies personalisierenCookies ablehnenCookies akzeptieren

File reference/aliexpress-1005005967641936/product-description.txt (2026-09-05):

TENSTAR ROBOT ESP32-C3 Entwicklungsboard ESP32 C3 SuperMini WiFi Bluetooth - AliExpress 502

Source: https://de.aliexpress.com/item/1005005967641936.html
Archived: 2026-09-05

AliExpress
AliExpress App herunterladen
Other/DE/
EUR
Willkommen
Anmelden / Registrieren
0
Einkaufswagen
TENSTAR ROBOT ESP32-C3 Entwicklungsboard ESP32 C3 SuperMini WiFi Bluetooth
  4.9  
489 Bewertungen
  ౹  
10.000+ verkauft
 
Ausgewähltes Produkt mit Spitzenqualität
 
Ende : 7. Sept. 23:59 CET
2,85€
 5,79€ sparen
8,64€
2,69€ 
≥ 2 Stück
2,59€ 
≥ 5 Stück
Preis inkl. MwSt. | Zölle werden an der Kasse berechnet  ; Zusätzlicher 1 % Rabatt
Mit PayPal Zahlung in 30 Tagen ohne Zinsen bezahlen.
KI-generierte Artikelübersicht

Haftungsausschluss: Dieser Inhalt wurde mithilfe von KI generiert und spiegelt nicht die Meinung des Verkäufers wider. Die Plattform und die Verkäufer übernehmen hierfür keine rechtliche Haftung.

TENSTAR ROBOT ESP32-C3 Entwicklungsboard Dieses SuperMini Development Board ist ideal für Entwickler und Hobbys. Mit dem ESP32-C3 bietet es leistungsstarke Funktionen in kompakter Form. Perfekt für Projekte mit WiFi und Bluetooth.
Leistungsstarkes Mikrocontroller-System Der ESP32-C3 unterstützt moderne Kommunikationsstandards wie WiFi und Bluetooth. Er ist bestens geeignet für IoT-Anwendungen und Smart Devices mit geringem Energieverbrauch.
Kompatibel mit gängigen Entwicklungsumgebungen Das Board ist kompatibel mit Arduino IDE und anderen gängigen Tools. Die einfache Einrichtung ermöglicht schnelle Prototypenentwicklung und schnelle Projektumsetzung.
Effiziente Stromversorgung und geringer Energieverbrauch Mit einer Supply Voltage von 1 V und niedrigem Dissipation Power ist das Board energiesparend. Ideal für batteriebetriebene Anwendungen und mobile Projekte.
Robustes Design für vielseitige Anwendungen Das SuperMini Development Board ist stabil und langlebig. Der Operating Temperature von 1 °C ermöglicht Einsatz in verschiedenen Umgebungen, auch bei Temperaturen nahe der Grenze.
Mehr
Weitere Preisinformationen 
Kundenbewertungen (489)
Spezifikationen
Übersicht
Laden
Das könnte Sie auch interessieren
Bewertungen | 4.9
 
 
488 Bewertungen
 
Alle von verifizierten Einkäufen
Kompatibilität : Vollständig kompatibel
88%
Funktionalität : Schnell
76%
Anwendungsbereich : Groß
67%
Alle Bewertungen (27) (20) (0)alles ok (23)funktioniert wie erwartet (20)gute qualität (14)schneller versand (12)alles ist richtig (10)schnelle lieferung (10)
5.0
5.0
5.0
5.0
5.0
5.0
Mehr anzeigen
Standardmäßig sortierenOriginalsprache anzeigen
Es ist ein sehr gutes Board; bei diesem Modell muss ich es nicht durch Drücken der Boot-Taste anschließen, wie bei anderen, die dies erfordern, damit der PC sie erkennt.
c***r | 25 Jan. 2026
 Hilfreich (0)   
Die Verarbeitungsqualität ist gut – die Chip-Antenne empfängt im Innenbereich ein ordentliches Signal. Getestet mit verschiedenen WLAN-Zugangspunkten rund um das Gebäude und alles funktioniert einwandfrei.
B***y | 30 Sept. 2025
 Hilfreich (0)   
Ich mag diese sehr Sie sind sehr klein, werden nicht heiß und haben eine gute WLAN-Reichweite. Sie haben auch einen C3 mit externer Antenne Ich habe alle meine alten ESP8266-Geräte damit ersetzt.
R***d | 01 Dez. 2025
 Hilfreich (0)   
Mehr anzeigen
Ähnliche Artikel
Previous
Seeed Studio XIAO für ESP32 C3 Mini Entwicklungsboard Seeeduino Xiao ESP32C3 Modul WiFi BlE5.0 RISC-V für Arduino
8,99€
5
1.000+ verkauft
0,5€ sparen
Auf AliExpress meistverkauft
1-10 Stück ESP32-C3 Entwicklungsboard mit ESP32 SuperMini Entwicklungsboard ESP32 WiFi Bluetooth mit 4M Flash C3
27,79€
(2,78€/Stück)
4.6
2.000+ verkauft
Auf AliExpress meistverkauft
Kostenloser Versand ab 10€
ESP32 C3 SuperMini Entwicklungsboard ESP32-C3 WiFi Bluetooth Modul für Arduino
2,69€
4.7
10.000+ verkauft
Jedes 2,59€, ≥ 2 Stücke
5,22€ sparen
ESP32-S3 Entwicklungsboard DevKitC-1 N8R2 N16R8 WiFi BT Modul 44-Pin Typ-C USB ESP32-S3 WROOM-1
5,99€
4.8
2.000+ verkauft
1,47€ sparen
Auf AliExpress meistverkauft
Werbeanzeige
ESP32-S3 2,4 GHz WiFi Bluetooth Modul ESP32-S3-WROOM-1 N16R8 N8R2 Entwicklungsboard CORE Board Typ-C ESP32 S3
6,59€
4.7
2.000+ verkauft
0,37€ sparen
Auf AliExpress meistverkauft
Werbeanzeige
Next
Spezifikationen
Hochbetriebenes Chemikalienunternehmen
Keine
Paket
SOP
ist kundenspezifisch
Ja
Verlustleistung
SuperMini Development Board
Versorgungsspannung
1
Typ
SPANNUNGSREGELER
Mehr anzeigen
Übersicht
Melden
Mehr anzeigen
Fragen und Antworten von Käufern (8)

Könnte dieses Board mit WLED geladen werden

Ja mit Wled esp Flasher, aber dieses Board sehr heiß :(

Welches Board in Arduino IDE auszuwählen?

Ich habe das ESP32C3DevModule Board def verwendet und es hat gut funktioniert

Hat dies eine WiFi-Antenne

Es verwendet eine kombinierte Wifi/Bluetooth-Antenne. Der mit "C3" gekennzeichnete Chip ist die Antenne auf denen, die ich erhalten habe.

Informationen zu Zusatzkosten
Bei von außerhalb der Europäischen Union gelieferten Artikeln fallen in Ihrem Land u. U. weitere MwSt.- und wenn anwendbar Zollgebühren an. Wenn AliExpress per Gesetz zur Erhebung der MwSt. verpflichtet ist, wird der Preis an der Kasse inklusive Mehrwertsteuer angezeigt. Für weitere Informationen zu diesen Kosten wenden Sie sich bitte an das Finanzamt bzw. die Zollbehörde Ihres Landes.
Verkauft durch TENSTAR ROBOT Store. Logistik durch AliExpress.
Informationen zur Produktkonformität
Haftungsausschluss
Haftungsausschluss: Bilder und Produktinformationen auf dieser Seite können automatisch von KI übersetzt worden sein. Diese Übersetzungen werden nur zur Bequemlichkeit und im Ist-Zustand bereitgestellt und können Ungenauigkeiten oder Inkonsistenzen enthalten.
2,85€ 8,64€
Preis inkl. MwSt. | Zölle werden an der Kasse berechnet  ; Zusätzlicher 1 % Rabatt
Verkauft von
TENSTAR ROBOT Store
(Händler)
 Kontaktieren
  
  
AliExpress-Verpflichtung
Pick-up points  
Kostenloser Versand über 10,00€  
Zustellung: Um Sep 10 - 15 
Kurierdienst:   DHL Paket   Hermes ,etc.  
Expresslieferung
 
1,00€ Coupon-Code für die verspätete Lieferung
 
Geld zurück bei defekt geliefertem Artikel
 
Geld zurück bei verlorenem Paket
 
Geld zurück bei Nichtlieferung in 40 Tagen
Rückgabe bis 90 Tage kostenlos
Sicherheit und Datenschutz persönliche Daten schützen
Sichere Zahlungen: Wir geben keine Ihrer personengebundenen Daten ohne Ihre Zustimmung an Dritte weiter.
Persönliche Angaben schützen: Wir schützen Ihre Privatsphäre und bewahren Ihre personengebundenen Daten sicher auf.
Menge
128 verfügbar
Jetzt kaufenIn den Warenkorb
 Teilen
 7609
  
TENSTAR ROBOT Store
98.3% Positives Feedback | 3311 Follower
 
Kontaktieren
Empfohlen von TENSTAR ROBOT Store
BMI160 GY-BMI160 6DOF 6-Achsen-Rate Gyro Schwerkraft-Beschleunigungsmesser-Sensormodul IIC I2C SPI Kommunikationsprotokoll 3–5 V
1,89€
4.9
5.000+ verkauft
Jedes 1,85€, ≥ 3 Stücke
3,84€ sparen
PIR Sensor HC-SR501 HC-SR602 HC-Sr505 Einstellen IR Pyroelektrische Infrarot Motion Detektor Modul Für Raspberry Pi Sensing Menschlichen Körper
1,45€
4.8
5.000+ verkauft
Jedes 1,39€, ≥ 3 Stücke
0,85€ sparen
TENSTAR UDA1334A DAC Modul UDA1334 I2S DAC Audio Stereo Decoder Modul Board Für Raspberry Pi
3,49€
5
442 verkauft
Jedes 3,29€, ≥ 2 Stücke
3,79€ sparen
TENSTAR 2 stücke UV Sensor GUVA-S12SD 240-370nm 3528 Solar Uv Intensität Modul DC 3,3-5 V Für Arduino/Himbeere pi
2,99€
(3,1€/Stück)
4.8
452 verkauft
Jedes 2,79€, ≥ 2 Stücke
3,24€ sparen
ESP32 Für Wemos D1 Mini D1 R32 WIFI Drahtlose Bluetooth Entwicklung Bord CH340 4M Speicher Ein ESP 32
5,09€
4.7
1.000+ verkauft
Jedes 4,79€, ≥ 2 Stücke
10,82€ sparen
Das könnte Sie auch interessieren
1-10 Stück ESP32-C3 Entwicklungsboard ESP32 SuperMini Entwicklungsboard ESP32 Entwicklungsboard WiFi Bluetooth
12,49€
(2,5€/Stück)
4.7
1.000+ verkauft
0,89€ sparen
Auf AliExpress meistverkauft
TENSTAR ESP32-S3 ESP32-C3 ESP32-H2 ESP32-C6 Entwicklungsboard WiFi Bluetooth Modul Single-Core SupmerMini XIAO
2,79€
4.9
10.000+ verkauft
3,15€ sparen
Kostenloser Versand ab 10€
Xiao esp32c6 winzige super mini board wi-fi und bluetooth 5,0 für arduino für seeed studio esp32 c6
9,05€
4.9
2.000+ verkauft
Auf AliExpress meistverkauft
Kostenloser Versand ab 10€
Werbeanzeige
ESP32-C3 MINI Development Board ESP32 SuperMini Development Board ESP32-C3 Development Board WiFi Bluetooth Erweiterungsboard
2,55€
4.8
10.000+ verkauft
Jedes 2,39€, ≥ 2 Stücke
5,42€ sparen
ESP ESP32-S3 CAM WiFi Bluetooth Development Board Modul Onboard ESP32-S3 N16R8 Dual TYPE-C OV2640 /OV5640/OV3660 Kamera
8,06€
4.6
3.000+ verkauft
Auf AliExpress meistverkauft
Kostenloser Versand ab 10€
NEUES ESP32-S3 Entwicklungsboard mit 2,4G WLAN BT Modul für AI IOT DIY ESP32-S3WROOM1 N16R8 MCU 44Pin Type-C 8M PSRAM
6,89€
4.9
5.000+ verkauft
0,36€ sparen
Auf AliExpress meistverkauft
Werbeanzeige
TOOLEYE 10-teiliges PCB-Bohrer-Set, Mikrobohrer, Leiterplatte, 1/8 Zoll Schaft, Mini-CNC-Bohrer, 0,1–3,175 mm Bohrwerkzeuge
2,79€
(0,28€/Stück)
4.8
10.000+ verkauft
Auf AliExpress meistverkauft
Kostenloser Versand ab 10€
Werbeanzeige
TENSTAR ESP32-C3 Supermini Plus Entwicklungsboard WiFi Bluetooth ESP32 C3 Super mini V2.0 Rotes Board
4,69€
4.9
10.000+ verkauft
5,73€ sparen
Kostenloser Versand ab 10€
Basic Starter Kit für ESP32 ESP-32S WIFI Development Board Project Learning Kit mit Tutorials ESP32 Kit mit Box
14,19€
4.8
2.000+ verkauft
Jedes 13,39€, ≥ 2 Stücke
36,49€ sparen
SONOFF Zigbee Smart TRV Gen2 Thermostatischer Heizkörperventil-Steuermotor TRV-ZBT Kompatibel mit Alexa, Google Home Assistant und Matter
31,79€
5
197 verkauft
43,9€ sparen
Auf AliExpress meistverkauft
Werbeanzeige
ESP32-32D ESP32-32U Entwicklungsboard mit GPIO-Erweiterungsplatine Kit BT WLAN-Modul USB Typ-C 38PIN CP2102 ESP32-DevKitC
5,19€
4.8
10.000+ verkauft
Auf AliExpress meistverkauft
Kostenloser Versand ab 10€
Werbeanzeige
Holyiot Nordic nRF54L15 Bluetooth Beacon mit 3-Achsen-Befestigungsmesser-Ble-Modul, geringer Stromverbrauch, IoT-Gerät für Smart Home
9,19€
5
800+ verkauft
Auf AliExpress meistverkauft
Nordic wohnkultur Kronleuchter für esszimmer glanz anhänger lichter hängen lampen für decke Leuchte innen beleuchtung
189,69€
3.7
17 verkauft
155,2€ sparen
Kostenloser Versand
Werbeanzeige
TENSTAR RP2040 Pro Micro Development Board 4 MB/16 MB Flash Dual-Core unterstützt Mciro Python kompatibel für Raspberry PI PICO
3,05€
4.9
5.000+ verkauft
3,88€ sparen
Kostenloser Versand ab 10€
1-10PCS MPU6050 GY-521 6DOF IMU-Modul mit 3-Achsen-Beschleunigungsmesser und Gyroskop für Arduino/Raspberry Pi
1,65€
4.6
2.000+ verkauft
0,07€ sparen
Auf AliExpress meistverkauft
12 V 200 Ah 100 Ah LiFePO4-Akku 2560 Wh Bluetooth BMS 140 Ah 24 V Fischboot-Akku 6000 Zyklen IP56 USB QC-Ladung EU Schnelle Lieferung
260,08€
472,87€
-45%
4.8
900+ verkauft
Auf AliExpress meistverkauft
Kostenloser Versand
Werbeanzeige
TENSTAR T-Display ESP32-D0WD CH9102 Chip 16 MB WiFi Und Bluetooth-Kompatibel Modul Entwicklung Bord 1,14 Zoll LCD Steuerung
10,39€
4.9
10.000+ verkauft
Jedes 9,79€, ≥ 2 Stücke
11,72€ sparen
1-10 stücke Original 0,96 zoll oled IIC Serielle Weiß OLED Display Modul 128X64 I2C SSD1306 12864 LCD Screen Board Für Arduino
2,19€
4.8
10.000+ verkauft
Auf AliExpress meistverkauft
Kostenloser Versand ab 10€
8TB tragbares Solid-State-Laufwerk, 32TB externes SSD mit großer Kapazität, USB3.1 Plug-and-Play, geeignet für Laptops/MAC/PC
17,19€
5
3 verkauft
9,67€ sparen
Werbeanzeige
ESP32 WiFi Bluetooth Entwicklungsboard Typ-C Micro USB CP2102 CH340C 30-Pin 38-Pin Dual-Core MCU Modul
2,45€
4.7
2.000+ verkauft
0,14€ sparen
Auf AliExpress meistverkauft
Werbeanzeige
TENSTAR RP2350 Red Board PICO2 Entwicklungsboard TYPE-C USB RP2350A Chip Mikrocontroller kompatibel mit Raspberry Pi PICO2
5,09€
4.9
5.000+ verkauft
5,74€ sparen
Kostenloser Versand ab 10€
Tragbare SSD-Festplatte 2TB Externe Festplatte Schnelle Datenübertragung USB-C Solid-State-Disk für Laptop, Mac, Windows-PC
10,19€
29,11€
-64%
5
30 verkauft
Frühbucherangebot, nur noch 2990 übrig
Kostenloser Versand
Werbeanzeige
TENSTAR NRF52840 Entwicklungsboard kompatibel mit Nice!Nano V2.0 Bluetooth-Lademanagement Pro Micro NRF52840
4,79€
4.9
2.000+ verkauft
3+, kein Zollaufschlag
5,97€ sparen
Kombi-Knaller
UN0 R3 Board ATmega328P Entwicklungsboard mit Stiftleiste und Kabel, kompatibel mit Arduino IDE-Projekten
3,59€
4.9
10.000+ verkauft
4,05€ sparen
Kostenloser Versand ab 10€
ESP32-C3 supermini wifi bluetooth-kompatibles board esp32 c3 supermini entwicklungs board iot board für arduino
3,39€
4.8
10.000+ verkauft
Jedes 3,25€, ≥ 2 Stücke
6,88€ sparen
ESP32-C3 ESP32-S3 ESP32-H2 ESP32-C6 Entwicklungsboard ESP32 C3 SuperMini WiFi Bluetooth ESP32C3
1,79€
4.8
5.000+ verkauft
Auf AliExpress meistverkauft
ESP32-S3 2,4GHz WiFi Bluetooth Modul ESP32-S3-N16R8 N8R2 Entwicklungsboard CORE Board Typ-C ESP32 S3
2,49€
4.8
1.000+ verkauft
Auf AliExpress meistverkauft
Kostenloser Versand ab 10€
Werbeanzeige
ESP32 Entwicklungsboard WiFi Bluetooth Modul Typ-C/Micro USB CH340C CP2102 30Pin 38Pin Erweiterungsplatine für Arduino
6,09€
4.7
2.000+ verkauft
0,45€ sparen
Auf AliExpress meistverkauft
Werbeanzeige
EstarDyn Omnidirektionales Mikrofonmodul I2S-Schnittstelle INMP441 MEMS Hochpräzise Stromsparend Ultra-kompaktes Format für ESP32
2,05€
4.9
2.000+ verkauft
Jedes 1,95€, ≥ 3 Stücke
2,41€ sparen
Werbeanzeige
Das SCD40 SCD41 Gas-Sensormodul erkennt CO2-Kohlendioxid-Temperatur und Luftfeuchtigkeit in einer Sensor-I2C-Kommunikation
14,59€
4.8
2.000+ verkauft
Jedes 13,89€, ≥ 2 Stücke
9,97€ sparen
Original Lenovo XT80 Sport-Funkkopfhörer mit Mikrofonen, LED-Leistungsanzeige, Hifi-Stereo-Sound, Bluetooth 5.3 TWS-Kopfhörer
15,49€
4.7
10.000+ verkauft
19,71€ sparen
Auf AliExpress meistverkauft
Werbeanzeige
1–10 Stück hochpräzise MEMS-Mikrofone MS3625 – I2S-Schnittstelle, kompatibel mit INMP441 und für ESP32 (omnidirektional)
1,65€
4.9
3.000+ verkauft
0,06€ sparen
Auf AliExpress meistverkauft
RP2040-Zero RP2040 für Raspberry Pi Mikrocontroller PICO Development Board Modul Dual-core Cortex M0 + Prozessor 2 MB Flash
2,65€
4.9
5.000+ verkauft
Jedes 2,49€, ≥ 2 Stücke
5,14€ sparen
RadioLink T12D T16D Fernbedienung mit Empfänger Unterstützt ELRS Hochfrequenz-Head für UAV FPV Ferngesteuertes Auto Roboter Virtuelle Spiele
17,39€
5
17 verkauft
7,81€ sparen
Bester Preis in ähnlichen Angeboten
Werbeanzeige
ESP32-C3 OLED-Entwicklungsboard mit 0,42 Zoll OLED-Modul, Keramikantenne, ESP32 Supermini-Entwicklungsboard, WLAN, Bluetooth
3,45€
4.9
5.000+ verkauft
Jedes 3,29€, ≥ 2 Stücke
3,28€ sparen
BIGTREETECH TMC2209 V1.3 Schrittmotortreiber UART VS TMC2208 TMC2130 3D-Druckerteile für Octopus V1.1 SKR 2 Board Ender 3 V2
4,79€
4.9
4.000+ verkauft
0,2€ sparen
Auf AliExpress meistverkauft
DT28F640J5A150 DA28F640J5A150 DA28F640 SSOP-56 10 teile/los
17,39€
2 verkauft
Individuell anpassbar
Werbeanzeige
ESP32 32D Entwicklungsboard / Modul Drahtloses WiFi-Bluetooth-Modul Ultra-Niedriger Stromverbrauch Dual-Core 30-Pin Smart Home
3,59€
4.8
10.000+ verkauft
8,79€ sparen
Auf AliExpress meistverkauft
0,42 Zoll OLED-Entwicklungsboard für ESP32-C3, WLAN-BT-Funkmodul mit Keramikantenne, SuperMini-Entwicklungsboard
3,85€
4.8
5.000+ verkauft
Jedes 3,69€, ≥ 2 Stücke
4,9€ sparen
Metall-Messschieber, digitales Pachometer, professionelles Messgerät, Messwerkzeuge, Holzbearbeitung, Dickenmessgerät, Tiefe, elektronisches Lineal
13,19€
18,58€
-29%
4.7
3.000+ verkauft
Auf AliExpress meistverkauft
Kostenloser Versand
Werbeanzeige
EstarDyn ESP32-C3 MINI Entwicklungsboard / ESP32 SuperMini Development WiFi Bluetooth Erweiterungsboard
2,55€
4.9
10.000+ verkauft
Jedes 2,39€, ≥ 2 Stücke
3€ sparen
Werbeanzeige
1-10 Stück 32D Entwicklungsboard WiFi+Bluetooth-kompatibel TYPE-C 30Pin Nodemcu Entwicklungsmodul
5,09€
4.9
2.000+ verkauft
Jedes 4,89€, ≥ 2 Stücke
10,82€ sparen
4TB Tragbare Externe Solid-State-Festplatte USB-C Robustes Design Stoßfeste Speicherlösung für Feldarbeit und Alltäglichen Datenspeicherung
14,39€
4.6
70 verkauft
10€ sparen
Werbeanzeige
ESP32C3 Entwicklungsboard Mini WLAN BT Modul Typ-C ESP32-C3 16-Pin RISC-V 32-Bit Single-Core Prozessor Erweiterungsplatine
8,39€
(2,8€/Stück)
4.6
1.000+ verkauft
Kostenloser Versand ab 10€
Werbeanzeige
ESP32 Entwicklungsboard 2,4G WLAN Bluetooth-Modul 30-Pin 38-Pin CP2102 Micro Type-C Ultra-Niedriger Stromverbrauch Dual-Core ESP-32
6,69€
4.9
1.000+ verkauft
Jedes 6,39€, ≥ 2 Stücke
8,18€ sparen
Effiziente Original Tragbare SSD-Festplatte USB3.1 Typ-C 1TB 4TB 128TB Große Kapazität Externe Solid-State-Festplatte Kompatibel
15,89€
24,45€
-35%
5
1 verkauft
Werbeanzeige
ESP32C6 Mini-Entwicklungsboard XIAO ESP32 C6-2.4 GHz WiFi6, BLE5.3, Zigbee Thread (802.15.4) ESP Rain Maker, AWS IoT, Microsoft Azure
16,49€
33,65€
-50%
4.9
1.000+ verkauft
Auf AliExpress meistverkauft
Werbeanzeige
TFT-Display 1,28 Zoll TFT-LCD-Anzeigemodul Runde RGB 240 * 240 GC9A01 Treiber 4-Draht-SPI-Schnittstelle 240 x 240 PCB
3,59€
4.9
5.000+ verkauft
Jedes 3,39€, ≥ 2 Stücke
2,02€ sparen
Andere suchten auch
Dieser Artikel gehört zur Home
Hilfe
Hilfe-Center, Streitigkeiten & Berichte, Rückgabe-und Erstattungsrichtlinie, RGE-Verletzung melden, DSA/OSA-Informationen , Integrität und Konformität , Transparenz zentrum, Beschwerdeeinstieg ohne Anmeldung, Rückerstattungsrichtlinie
Mehrsprachige AliExpress-Websites
Pусский, Portuguese, Spanish, French, German, Italian, Dutch, Turkish, Japanese, Korean, Thai, Arabic, Hebrew, Polish
Browse by Category
Alle beliebten , Produkt , Aktion , Günstiger Preis , Toller Wert , Bewertungen , Wiki, Video
Alibaba Group
Alibaba Group Website, AliExpress, Alimama, Fliggy, Alibaba Cloud, Alibaba International, AliTelecom, DingTalk, Juhuasuan, Taobao Marketplace, Tmall, Taobao Global, AliOS, 1688
Intellectual Property Protection - Privacy Policy - Cookie‑Einstellungen - Sitemap - AliExpress.com Nutzungsbedingungen - Informationen für EU-Verbraucher - Rechtliche Hinweise / Impressum - Transaktionsdienstleistungsvertrag für Verbraucher außerhalb der EU/des Vereinigten Königreichs - Allgemeine Geschäftsbedingungen für EU/EEA/UK-Verbraucher - User Information Legal Enquiry Guide ©️ 2010-2025 AliExpress.com. All rights reserved.
Cookie-Einstellungen
Später
Wir verwenden Cookies und ähnliche Technologien für die Verbesserung des Benutzererlebnisses und die Personalisierung von Werbung.Auf diese Weise können wir und Drittanbieter Ihnen sowohl auf als auch außerhalb unserer Websites Inhalte, Marketing und Werbung anbieten, die Ihnen gefallen könnten. Ihre Einstellungen können Sie jederzeit unter Cookie-Einstellungen“ ändern. Weitere Informationen finden Sie in unserem Cookie-Hinweis.
Cookies personalisierenCookies ablehnenCookies akzeptieren

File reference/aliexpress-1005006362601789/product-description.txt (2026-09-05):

LM2596 DC-DC Buck Converter 3,2V-46V auf 1,25V-35V

Source: https://de.aliexpress.com/item/1005006362601789.html
Archived: 2026-09-05

AliExpress
AliExpress App herunterladen
Other/DE/
EUR
Willkommen
Anmelden / Registrieren
0
Einkaufswagen
1-10PCS LM2596 DC zu DC Buck Converter Spannungsregler 3,2V-46V zu 1,25V-35V Buck Converter Netzteil Step Down Modul
  4.8  
181 Bewertungen
  ౹  
1.000+ verkauft
 
Ende : 7. Sept. 23:59 CET
1,29€
 0,04€ sparen
1,33€
Preis inkl. MwSt. | Zölle werden an der Kasse berechnet  ; Zusätzlicher 5 % Rabatt
Mit PayPal Zahlung in 30 Tagen ohne Zinsen bezahlen.
0,79€ Rabatt ab 16,78€
Farbe: 1 PCS
KI-generierte Artikelübersicht

Haftungsausschluss: Dieser Inhalt wurde mithilfe von KI generiert und spiegelt nicht die Meinung des Verkäufers wider. Die Plattform und die Verkäufer übernehmen hierfür keine rechtliche Haftung.

Leistungsstarker DC-DC Buck Converter Der LM2596S Spannungsregler wandelt Eingangsspannungen von 3,2 V bis 46 V effizient auf 1,25 V bis 35 V ab. Perfekt für verschiedene Stromversorgungsanwendungen in der Elektronik.
Hohe Wirkungsgrad bis zu 92 % Mit einem maximalen Wirkungsgrad von 92 % minimiert der Modul Energieverluste. Ideal für batteriebetriebene Geräte und Anwendungen, bei denen Energieeffizienz entscheidend ist.
Maximale Ausgangsstromstärke von 3 A Der Converter unterstützt eine maximale Ausgangsstromstärke von 3 A, was ihn zu einer stabilen Lösung für leistungsbedürftige Schaltungen macht.
Stufenlos einstellbare Ausgangsspannung Der anpassbare Ausgang ermöglicht eine präzise Spannungsregelung zwischen 1,25 V und 35 V. Optional auch mit fester Ausgangsspannung erhältlich.
Robustes Design für breite Einsatzbedingungen Betriebstemperatur von -40 °C bis +85 °C ermöglicht den Einsatz in extremen Umgebungen. Ideal für industrielle, mobile und Außenanwendungen.
Mehr
Weitere Preisinformationen 
Kundenbewertungen (181)
Spezifikationen
Übersicht
Laden
Das könnte Sie auch interessieren
Bewertungen | 4.8
 
 
181 Bewertungen
 
Alle von verifizierten Einkäufen
Kompatibilität : Vollständig kompatibel
82%
Funktionalität : Schnell
8%
Anwendungsbereich : Groß
68%
Alle Bewertungen (33) (5) (3)schnelle lieferung (9)zuverlässige leistung (8)hervorragende verarbeitungsqualität (5)wie beschrieben (5)gut verpackt (4)erfüllt die erwartungen (4)
5.0
5.0
5.0
5.0
5.0
5.0
Mehr anzeigen
Standardmäßig sortierenOriginalsprache anzeigen
Farbe:Rot
Es funktioniert gut, es nimmt 24V an und reduziert es auf 3V; ich habe 6 Einheiten gekauft und alle 6 funktionieren einwandfrei.
+3
AliExpress-Einkäufer | 21 Mai 2026
 Hilfreich (1)   
Farbe:Weizen
5 Stück DC/DC-Wandler LM2596 schnell und in gutem Zustand erhalten. Nur CV-Einstellungen. Ich habe sie bereits zuvor gekauft und getestet, und sie funktionieren einwandfrei. ICH EMPFEHLE ES.
+6
AliExpress-Einkäufer | 12 Mai 2026
 Hilfreich (0)   
Farbe:GRÜNE JADE
Ich habe das Teil verwendet, um einen USB-betriebenen Kamera an meinen 3D-Drucker anzuschließen. Ich habe es an die 12V-Hauptversorgung auf der Platine angelötet und es auf 5V eingestellt. Ein altes USB-Kabel habe ich benutzt, um die Kabel am Ausgang direkt an die Kamera anzulöten. Funktioniert einwandfrei.
N***U | 19 Apr. 2026
 Hilfreich (0)   
Mehr anzeigen
Ähnliche Artikel
Previous
1-10PCS MT3608 Boost Modul DC-DC Step Up Converter Booster Netzteil Modul Bord 2A Max 2V-24V Zu 5/9/12/28V für Arduino
0,88€
4.8
10.000+ verkauft
0,03€ sparen
Auf AliExpress meistverkauft
1–100 Stück MT3608 DC-DC-Boost-Modul – 28 V 2 A Step-Up-Leistungsmodul für Arduino, Batterie und DIY-Elektronikprojekte
3,79€
(0,38€/Stück)
4.6
800+ verkauft
0,18€ sparen
Auf AliExpress meistverkauft
Einstellbarer Ausgang LM2596S Step Down Modul DC zu DC Buck Converter Spannungsregler Konvertierung Netzteilmodul LM2596
8,39€
(0,84€/Stück)
-11%
4.9
5.000+ verkauft
3+, kein Zollaufschlag
Auf AliExpress meistverkauft
Kombi-Knaller
MT3608 DC-DC Einstellbares Boost-Modul 2A Aufwärtswandlerplatte Step-Up-Modul TYPE-C MICRO USB 2V-24V zu 5V 9V 12V 28V
1,05€
4.6
3.000+ verkauft
0,01€ sparen
Auf AliExpress meistverkauft
1–10 Stück LM2596 DC-DC-Abwärtswandler, 3,0–40 V auf 1,5–35 V, Abwärtsmodul
4,18€
(0,84€/Stück)
4.9
211 verkauft
3+, kein Zollaufschlag
Kostenloser Versand
Kombi-Knaller
Next
Spezifikationen
Hochbetriebenes Chemikalienunternehmen
Keine
ist kundenspezifisch
Ja
Modellnummer
LM2596S
Verlustleistung
.
Versorgungsspannung
3.2-46 V
Anwendung
.
Mehr anzeigen
Artikelanleitungen und Dokumente
Benutzerhandbuch
Anzeigen
Übersicht
Melden
Mehr anzeigen
Informationen zu Zusatzkosten
Bei von außerhalb der Europäischen Union gelieferten Artikeln fallen in Ihrem Land u. U. weitere MwSt.- und wenn anwendbar Zollgebühren an. Wenn AliExpress per Gesetz zur Erhebung der MwSt. verpflichtet ist, wird der Preis an der Kasse inklusive Mehrwertsteuer angezeigt. Für weitere Informationen zu diesen Kosten wenden Sie sich bitte an das Finanzamt bzw. die Zollbehörde Ihres Landes.
Verkauft durch HuiShengDongye Store. Logistik durch AliExpress.
Informationen zur Produktkonformität
Haftungsausschluss
Haftungsausschluss: Bilder und Produktinformationen auf dieser Seite können automatisch von KI übersetzt worden sein. Diese Übersetzungen werden nur zur Bequemlichkeit und im Ist-Zustand bereitgestellt und können Ungenauigkeiten oder Inkonsistenzen enthalten.
1,29€ 1,33€
Preis inkl. MwSt. | Zölle werden an der Kasse berechnet  ; Zusätzlicher 5 % Rabatt
Farbe: 1 PCS
 
Bearbeiten
Verkauft von
HuiShengDongye Store
(Händler)
 Kontaktieren
  
  
AliExpress-Verpflichtung
Pick-up points  
Kostenloser Versand über 10,00€  
Zustellung: Um Sep 10 - 15 
Kurierdienst:   DHL Paket   Hermes ,etc.  
Expresslieferung
 
1,00€ Coupon-Code für die verspätete Lieferung
 
Geld zurück bei defekt geliefertem Artikel
 
Geld zurück bei verlorenem Paket
 
Geld zurück bei Nichtlieferung in 40 Tagen
Rückgabe bis 90 Tage kostenlos
Sicherheit und Datenschutz persönliche Daten schützen
Sichere Zahlungen: Wir geben keine Ihrer personengebundenen Daten ohne Ihre Zustimmung an Dritte weiter.
Persönliche Angaben schützen: Wir schützen Ihre Privatsphäre und bewahren Ihre personengebundenen Daten sicher auf.
Menge
Nur 5 übrig
Jetzt kaufenIn den Warenkorb
 Teilen
 223
  
HuiShengDongye Store
97.4% Positives Feedback | 2795 Follower
 
Kontaktieren
Empfohlen von HuiShengDongye Store
500 Teile/los 0,1 UF-1000 UF 24 Werte Aluminium-elektrolytkondensatoren 10-50 V mix elektrolytkondensator Assorted kit und aufbewahrungsbox
3,79€
6 verkauft
4,82€ sparen
MB-102 Prototyp-Steckplatine 830 Punkte Lötfreie PCB-Steckplatine Jumper-Kabel DIY Dupont-Kabel für Arduino-Kit
0,52€
5
6 verkauft
1,25€ sparen
Neue Ankunft 4A Bis 6A 24V Stabile High Power 100W Schaltnetzteil Bord AC DC Power Modul transformator Großhandel
6,99€
4.8
20 verkauft
0,4€ sparen
Kostenloser Versand ab 10€
XH-M604 Batterieladegerät Steuermodul DC 6–60 V Speicher Lithium-Batterie Ladesteuerschalter Schutzplatine
4,19€
5
9 verkauft
0,17€ sparen
Kostenloser Versand ab 10€
Digitale Verstärkerplatine TPA3116DA TPA3116 150 W D2 Monokanal Digital Power Audio Verstärkerplatine XH-M544 DC 12 V 24 V
4,89€
4.4
83 verkauft
0,35€ sparen
Kostenloser Versand ab 10€
ESP32-S3 Supermini Entwicklungsboard WiFi Bluetooth 5.0 Ultra-Kompakte Größe ESP32 S3 ESP32-S3FH4R2 Für IDE Für Micropython
3,29€
5
15 verkauft
3,86€ sparen
Das könnte Sie auch interessieren
10 Stück MT3608 DC-DC TYPE-C Mikro-Einstellbares Boost-Modul 2A DC-Leistungs-Step-Up-Konverter-Modul 2V-24V zu 5V 9V 12V 28V
3,45€
(0,34€/Stück)
4.9
286 verkauft
0,16€ sparen
Kostenloser Versand ab 10€
1-10PCS XL6009 4A Boost Converter Step Up Einstellbar 15W 5-32V zu 5-50V DC-DC Netzteil Modul LM2577 Step-up Modul
1,39€
1,59€
-12%
4.7
2.000+ verkauft
3+, kein Zollaufschlag
Auf AliExpress meistverkauft
Kombi-Knaller
XL6009 DC-DC-Booster-Modul. Der Ausgang des Netzteilmoduls ist einstellbar. Super LM2577 Step-up-Modul mit LED-Voltmeter
1,19€
4.8
426 verkauft
3+, kein Zollaufschlag
0,29€ sparen
Kombi-Knaller
5 Stück MT3608 DC-DC Aufwärtswandler Booster-Stromversorgungsmodul Boost-Step-up-Board MAX Ausgang 28V 2A
1,79€
4.7
5.000+ verkauft
0,16€ sparen
Auf AliExpress meistverkauft
5A DC-DC Step Up Power Module Boost Volt Converter 3,3V-35V zu 5V 6V 9V 12V 24V XL6019
1,59€
4.8
4.000+ verkauft
3+, kein Zollaufschlag
0,37€ sparen
Kombi-Knaller
1-10 stücke Original 0,96 zoll oled IIC Serielle Weiß OLED Display Modul 128X64 I2C SSD1306 12864 LCD Screen Board Für Arduino
2,19€
4.8
10.000+ verkauft
Auf AliExpress meistverkauft
Kostenloser Versand ab 10€
WEP Entlötstation 4-in-1 Digitale Entlötpistole Heißluft-Heißpistole Elektrische Lötstation, Lokale Lieferung
215,39€
4.9
25 verkauft
215,39€ sparen
Kostenloser Versand
Werbeanzeige
Mt3608 TYPE-C/usb 2a max DC-DC step up power modul booster power modul 2-24v zu 5v/9v/12v/28v
2,79€
(0,56€/Stück)
4.6
800+ verkauft
3+, kein Zollaufschlag
0,02€ sparen
Kombi-Knaller
TENSTAR 3 Stück XL6019 (XL6009 Upgrade) 20 W 5–32 V auf 1,3–35 V automatisches Step-Up-Step-Down-Gleichstrom-einstellbares Netzteilmodul
4,39€
(1,87€/Stück)
4.9
4.000+ verkauft
Jedes 4,19€, ≥ 2 Stücke
4,95€ sparen
DalyBMS LiFePo4 4S 100A 12V 8S 24V 250A 16S 300A 400A mit Bluetooth RS485 CAN NTC-Funktion für E-Bike-Wechselrichter Golfcart
37,59€
4.8
1.000+ verkauft
10,6€ sparen
Kostenloser Versand
Werbeanzeige
LM2596 DC-DC 3A Einstellbares Abwärtsmodul LM2596 Konstantstrom-Spannungsregler Hohe Effizienz Niedrige Hitze
1,79€
4.8
4.000+ verkauft
3+, kein Zollaufschlag
4,38€ sparen
Kombi-Knaller
Estardyn XL4015 5A DC-DC Step-Down-Buck-Konverter, einstellbares 4-38V auf 1,25-36V Festfrequenz-Stromversorgungsmodul
2,79€
5
212 verkauft
3+, kein Zollaufschlag
3,24€ sparen
Kombi-Knaller
Werbeanzeige
TOOLEYE 10-teiliges PCB-Bohrer-Set, Mikrobohrer, Leiterplatte, 1/8 Zoll Schaft, Mini-CNC-Bohrer, 0,1–3,175 mm Bohrwerkzeuge
2,79€
(0,28€/Stück)
4.8
10.000+ verkauft
Auf AliExpress meistverkauft
Kostenloser Versand ab 10€
Werbeanzeige
XL4015 E1 5A DC zu DC CC CV Lithium Batterie Step down Lade Board Led Power Converter Lithium Ladegerät Modul
1,75€
4.6
1.000+ verkauft
Auf AliExpress meistverkauft
Kostenloser Versand ab 10€
Werbeanzeige
1-10 Stück MP1584EN Einstellbarer 3A DC-DC-Wandler Step-Down-Spannungsregler-Modul Ersatz für LM2596s MP1584 DC-DC-Buck-Board
1,89€
5
45 verkauft
2,13€ sparen
Kostenloser Versand ab 10€
Werbeanzeige
18V Makita Original-Akku, LED-Display, wiederaufladbarer Werkzeugakku für Makita LXT-Serie Elektrowerkzeug-Akku & Ladegerät
17,49€
82,31€
-78%
2 verkauft
Frühbucherangebot, nur noch 3 übrig
Kostenloser Versand
Werbeanzeige
Lm2596 buck 3a DC-DC spannungs verstellbares Step-Down-Leistungs modul + blaues LED-Voltmeter
2,27€
2,29€
4.7
1.000+ verkauft
3+, kein Zollaufschlag
Kombi-Knaller
ANENG SZ308 Rechteckwellen-Digitaltester 1999, zählt HFE-Trioden-Summer-Multimeter, AC/DC-Spannung, 10 A, Strommultimeter, Messgerät
4,59€
4.6
5.000+ verkauft
Auf AliExpress meistverkauft
Kostenloser Versand ab 10€
8TB tragbares Solid-State-Laufwerk, 32TB externes SSD mit großer Kapazität, USB3.1 Plug-and-Play, geeignet für Laptops/MAC/PC
17,19€
5
3 verkauft
9,67€ sparen
Werbeanzeige
1-10PCS XL6019 DC-DC Step Up Power Modul DC-DC Boost Volt Konverter Einstellbare Netzteil ausgang 3V-40V Zu 5V-45V Versorgung
1,79€
1,79€
4.7
395 verkauft
3+, kein Zollaufschlag
Kombi-Knaller
Mini DC-DC 12-24V bis 5V 3A Step Down Netzteil Modul Spannung Buck Converter einstellbar 97,5% 1,8V 2,5V 3,3V 5V 9V 12V
0,39€
0,43€
-10%
4.6
3.000+ verkauft
Individuell anpassbar
Tragbare SSD-Festplatte 2TB Externe Festplatte Schnelle Datenübertragung USB-C Solid-State-Disk für Laptop, Mac, Windows-PC
10,19€
29,11€
-64%
5
30 verkauft
Frühbucherangebot, nur noch 2990 übrig
Kostenloser Versand
Werbeanzeige
40-PIN Dupont-Kabel, Stecker auf Stecker, Buchse auf Buchse, Stecker auf Buchse, Jumper-Kabel 10cm 15cm 20cm 30cm 40cm für Arduino DIY KIT
0,99€
1,25€
-20%
4.9
10.000+ verkauft
3+, kein Zollaufschlag
Auf AliExpress meistverkauft
Kombi-Knaller
1-10PCS XL6009 4A Boost Converter Step Up Einstellbar 15W 5-32V zu 5-50V DC-DC Netzteil Modul LM2577 Step-up Modul
6,45€
(1,29€/Stück)
4.9
448 verkauft
3+, kein Zollaufschlag
6,46€ sparen
Kombi-Knaller
1/5/10 Stück DC-DC einstellbares Step-Down 5A Netzteilmodul großer Strom große Leistung XL4005 DSN5000 über LM2596 hinaus
4,49€
(0,9€/Stück)
4.9
1.000+ verkauft
0,23€ sparen
Kostenloser Versand ab 10€
Lm2596 DC-DC Abwärts wandler modul 3a einstellbares Abwärts modul LM2596S-ADJ Spannungs regler 24V 12V 5V 3V lm2596s
1,15€
4.8
3.000+ verkauft
Auf AliExpress meistverkauft
Kostenloser Versand ab 10€
Werbeanzeige
TENSTAR 4 Stück roter XL4015 5A DC-DC-Stromrichter 8–34 V auf 1,25–32 V CC CV LED-Treiber Step-Down-Board Lithium-Lademodul
6€
(1,5€/Stück)
4.9
1.000+ verkauft
3+, kein Zollaufschlag
6,01€ sparen
Kombi-Knaller
LM2596 DC-DC Abwärtswandler Spannungsregler 4V ~ 40 bis 1,3V-37V LED-Anzeige Voltmeter Buck-Adapter Einstellbare Stromversorgung
2,45€
4.8
4.000+ verkauft
1,1€ sparen
Auf AliExpress meistverkauft
Werbeanzeige
1-10PCS LX8015 DC-DC Einstellbare Step Down Power Modul 5-80V zu 1-62V 1,5A Konverter für Solar Energie Schaltung Projekte XL7015
1,79€
4.9
148 verkauft
3+, kein Zollaufschlag
0,01€ sparen
Kombi-Knaller
1-10 Stück BME280 BMP280 5 V 3,3 V Digitalsensor Temperatur Luftfeuchtigkeit Luftdruckmodul I2C SPI für Arduino
4,59€
4.8
5.000+ verkauft
Auf AliExpress meistverkauft
Kostenloser Versand ab 10€
RadioLink T12D T16D Fernbedienung mit Empfänger Unterstützt ELRS Hochfrequenz-Head für UAV FPV Ferngesteuertes Auto Roboter Virtuelle Spiele
17,39€
5
17 verkauft
7,81€ sparen
Bester Preis in ähnlichen Angeboten
Werbeanzeige
MT3608 Boost-Konverter-Modul DC-DC Step-Up 2A 2V-24V zu 5V/12V/28V Einstellbare Stromversorgungsplatine für Arduino LED-Treiber
4,09€
(1,62€/Stück)
4.9
800+ verkauft
4,09€ sparen
Kostenloser Versand ab 10€
Werbeanzeige
ESP32-32D ESP32-32U Entwicklungsboard mit GPIO-Erweiterungsplatine Kit BT WLAN-Modul USB Typ-C 38PIN CP2102 ESP32-DevKitC
5,19€
4.8
10.000+ verkauft
Auf AliExpress meistverkauft
Kostenloser Versand ab 10€
Werbeanzeige
10-50 Stück M4 M5 M6 M8 Gewindeeinsatzmuttern aus Zinklegierung für Holz, Flansch-Sechskant-Antriebskopf, Möbelmuttern, Auswahl der Länge 8 mm bis 25 mm
1,79€
4.8
5.000+ verkauft
0,04€ sparen
Kostenloser Versand ab 10€
Werbeanzeige
1–10 Stück DC-DC SX1308 Step-UP einstellbares Leistungsmodul Step Up Boost Converter 2–24 V auf 2–28 V 2 A
0,96€
4.7
164 verkauft
0,03€ sparen
Kostenloser Versand ab 10€
1-20PCS XL6009 4A Boost Converter Step Up Einstellbar 15W 5-32V zu 5-50V DC-DC Netzteil Modul LM2577 Step-up Modul
4,39€
(0,88€/Stück)
4.8
800+ verkauft
3+, kein Zollaufschlag
0,49€ sparen
Kombi-Knaller
USB-zu-RS485-Isolationsmodul, 485-Modul, 485-Kommunikationsmodul, Original FT232RNL-REEL Chip + EXAR SP485 921600bps
6,99€
5
58 verkauft
Werbeanzeige
ESP32-S3 WLAN-BT-Modul Entwicklungsboard für Arduino IDE ESP32-S3 N16R8 N8R2 44-Pin Typ-C 16MB Flash 8M PSRAM ESP32 S3
6,99€
4.9
50.000+ verkauft
6,99€ sparen
Kostenloser Versand ab 10€
DC zu DC 400 W 15 A (max.), 8,5–50 V auf 10–60 V Modul, Step-Up-Boost-Konverter, Konstantstrom-Netzteil, LED-Treiber, Spannung, Ladegerät
31,79€
(3,18€/Stück)
4.8
5.000+ verkauft
3+, kein Zollaufschlag
70,39€ sparen
Kombi-Knaller
Hochgeschwindigkeits-SSD Tragbare Externe Festplatte 2TB 4TB Mass-Solid-State-Festplatte für Laptop, Mac, PC, Notebook, Mobiltelefon
14,19€
5
1 verkauft
10,28€ sparen
Werbeanzeige
LM2596S Step Down Modul DC zu DC Netzteil Hohe Effizienz Für Buck Converter Einstellbare Spannung Regler ConversionCircuit
1,72€
1,75€
4.9
500+ verkauft
3+, kein Zollaufschlag
Kombi-Knaller
1-100PCS IR Infrarot Hindernis Vermeidung Sensor Modul für Arduino Smart Car Robot 3-Draht Reflektierende photoelektrische Neue
31,39€
(0,31€/Stück)
4.8
230 verkauft
23,68€ sparen
MWNKDS 4S 12,8V 50Ah LiFePO4 Batterie 1200W Lithium-Eisenphosphat-Batterie mit LCD-Display 14,6V 10A Ladegerät für Wohnmobil-Solar-Backup
25,19€
41,98€
-39%
Kostenloser Versand
Werbeanzeige
DC-DC 24V/12V Zu 5V 5A Step Down Netzteil Buck Converter Ersetzen LM2596S Einstellbare USB Step-down Lade Modul Für Telefon
2,19€
4.8
2.000+ verkauft
3+, kein Zollaufschlag
0,33€ sparen
Kombi-Knaller
5 Stück/Mini560 5A DC-DC Mini560 PRO Step-Down stabilisiertes Spannungsversorgungsmodul 6–30 V bis hocheffizienter Ausgang 3,3 V 5 V 9 V 12 V
4,09€
(0,82€/Stück)
4.9
157 verkauft
Kostenloser Versand ab 10€
5PCS 100% New TLE7209-2R TLE6209R TLE 7209 6209 DSO-20 8V-40V SPI IC CHIP NEW STOCK
9,03€
5
59 verkauft
Kostenloser Versand ab 10€
Werbeanzeige
Typ-C Micro-USB-Schnittstellenanschluss 5V 1A 18650 Lithium-Batterie-Lademodul Ladeplatte mit Doppelschutzfunktionen
3,89€
(0,42€/Stück)
4.9
215 verkauft
4,57€ sparen
Auf AliExpress meistverkauft
Werbeanzeige
5PCS MT3608 DC-DC Step Up Boost Power Converter 2A Modul Einstellbare Step Up Spannung Regler Bord Spannung 2-24V zu 5V-28V Out
2,89€
(1,22€/Stück)
5
108 verkauft
Jedes 2,75€, ≥ 2 Stücke
3,26€ sparen
Andere suchten auch
Ähnliche Suche
300w dc dc converter
dc dc converter high power
high power ac dc converter
Ranking-Keywords
dc dc converter
step up dc dc converter
dc dc convert
dc converter 250v
dc dc converter 24v 16v
dc konverter
dc adapter lg 26lv5500
aliexpress dc dc converter
dc dc converter 5v usb
netzteil 230v auf 12v 1000w
haljia pwm 0 10v digital analog signal tranformers konverter modul pmw zu spannung wandlermodul review
dc dc buck converter 10a
Dieser Artikel gehört zur Home
Hilfe
Hilfe-Center, Streitigkeiten & Berichte, Rückgabe-und Erstattungsrichtlinie, RGE-Verletzung melden, DSA/OSA-Informationen , Integrität und Konformität , Transparenz zentrum, Beschwerdeeinstieg ohne Anmeldung, Rückerstattungsrichtlinie
Mehrsprachige AliExpress-Websites
Pусский, Portuguese, Spanish, French, German, Italian, Dutch, Turkish, Japanese, Korean, Thai, Arabic, Hebrew, Polish
Browse by Category
Alle beliebten , Produkt , Aktion , Günstiger Preis , Toller Wert , Bewertungen , Wiki, Video
Alibaba Group
Alibaba Group Website, AliExpress, Alimama, Fliggy, Alibaba Cloud, Alibaba International, AliTelecom, DingTalk, Juhuasuan, Taobao Marketplace, Tmall, Taobao Global, AliOS, 1688
Intellectual Property Protection - Privacy Policy - Cookie‑Einstellungen - Sitemap - AliExpress.com Nutzungsbedingungen - Informationen für EU-Verbraucher - Rechtliche Hinweise / Impressum - Transaktionsdienstleistungsvertrag für Verbraucher außerhalb der EU/des Vereinigten Königreichs - Allgemeine Geschäftsbedingungen für EU/EEA/UK-Verbraucher - User Information Legal Enquiry Guide ©️ 2010-2025 AliExpress.com. All rights reserved.
Cookie-Einstellungen
Später
Wir verwenden Cookies und ähnliche Technologien für die Verbesserung des Benutzererlebnisses und die Personalisierung von Werbung.Auf diese Weise können wir und Drittanbieter Ihnen sowohl auf als auch außerhalb unserer Websites Inhalte, Marketing und Werbung anbieten, die Ihnen gefallen könnten. Ihre Einstellungen können Sie jederzeit unter Cookie-Einstellungen“ ändern. Weitere Informationen finden Sie in unserem Cookie-Hinweis.
Cookies personalisierenCookies ablehnenCookies akzeptieren

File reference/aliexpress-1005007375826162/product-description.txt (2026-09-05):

50 Stück 1W 1% 0.12 0.18 0.2 K 1.5 3.9 4.7 6.8 7.5 68R 75 82 91R 100 110 120 130 150R 680 200 220 240 270R 300 330R 360 390 820 470 Ω OHM Dip-Metallfilm-Farbring widerstand - AliExpress 502

Source: https://de.aliexpress.com/item/1005007375826162.html
Archived: 2026-09-05

AliExpress
AliExpress App herunterladen
Other/DE/
EUR
Willkommen
Anmelden / Registrieren
0
Einkaufswagen
50 Stück 1W 1% 0.12 0.18 0.2 K 1.5 3.9 4.7 6.8 7.5 68R 75 82 91R 100 110 120 130 150R 680 200 220 240 270R 300 330R 360 390 820 470 Ω OHM Dip-Metallfilm-Farbring widerstand
  4.8  
26 Bewertungen
  ౹  
163 verkauft
1,99€/Viel 
50Stück ; Preis inkl. MwSt. | Zölle werden an der Kasse berechnet  ; Zusätzlicher 6 % Rabatt
Mit PayPal Zahlung in 30 Tagen ohne Zinsen bezahlen.
0,92€ Rabatt ab 31,46€
Widerstand: 51K ohm
0.1 ohm
0.12 ohm
0.15 ohm
0.18 ohm
0.2 ohm
0.22 ohm
0.24 ohm
0.27 ohm
0.3 ohm
0.33 ohm
0.36 ohm
0.39 ohm
0.43 ohm
0.47 ohm
0.5 ohm
0.56 ohm
0.62 ohm
0.68 ohm
0.75 ohm
0.82 ohm
0.91 ohm
1 ohm
1.2 ohm
1.5 ohm
1.8 ohm
2.0 ohm
2.2 ohm
2.4 ohm
2.7 ohm
3.0 ohm
3.3 ohm
3.6 ohm
3.9 ohm
4.3 ohm
4.7 ohm
5.1 ohm
5.6 ohm
6.2 ohm
6.8 ohm
7.5 ohm
8.2 ohm
9.1 ohm
10 ohm
12 ohm
15 ohm
18 ohm
20 ohm
22 ohm
24 ohm
27 ohm
30 ohm
33 ohm
36 ohm
39 ohm
43 ohm
47 ohm
51 ohm
56 ohm
62 ohm
68 ohm
75 ohm
82 ohm
91 ohm
100 ohm
120 ohm
130 ohm
150 ohm
160 ohm
180 ohm
200 ohm
220 ohm
240 ohm
270 ohm
300 ohm
330 ohm
360 ohm
390 ohm
430 ohm
470 ohm
510 ohm
560 ohm
620 ohm
680 ohm
750 ohm
820 ohm
910 ohm
1K ohm
1.2K ohm
1.3K ohm
1.5K ohm
1.8K ohm
2.0K ohm
2.2K ohm
2.4K ohm
2.7K ohm
3.0K ohm
3.3K ohm
3.6K ohm
3.9K ohm
4.3K ohm
4.7K ohm
5.1K ohm
5.6K ohm
6.2K ohm
6.8K ohm
7.5K ohm
8.2K ohm
9.1K ohm
10K ohm
12K ohm
13K ohm
15K ohm
18K ohm
20K ohm
22K ohm
24K ohm
27K ohm
30K ohm
33K ohm
36K ohm
39K ohm
43K ohm
47K ohm
51K ohm
56K ohm
62K ohm
68K ohm
75K ohm
82K ohm
91K ohm
100K ohm
110K ohm
120K ohm
130K ohm
150K ohm
160K ohm
180K ohm
200K ohm
220K ohm
240K ohm
270K ohm
300K ohm
330K ohm
360K ohm
390K ohm
430K ohm
470K ohm
510K ohm
560K ohm
620K ohm
680K ohm
750K ohm
820K ohm
910K ohm
1M ohm
1.2M ohm
1.5M ohm
1.8M ohm
2.0M ohm
2.2M ohm
3.3M ohm
4.7M ohm
KI-generierte Artikelübersicht

Haftungsausschluss: Dieser Inhalt wurde mithilfe von KI generiert und spiegelt nicht die Meinung des Verkäufers wider. Die Plattform und die Verkäufer übernehmen hierfür keine rechtliche Haftung.

50 Stück hochwertige Metallfilm-Widerstände Dieser Set enthält 50 Stück Metal Film Resistor mit präziser 1% Genauigkeit. Perfekt für Elektronikprojekte, Reparaturen und Prototypenentwicklung in der Praxis.
Umfangreiche Widerstandswerte im Lieferumfang Die Widerstände reichen von 0,1 Ω bis 1,5 MΩ, inklusive gängiger Werte wie 100 Ω, 1 kΩ, 10 kΩ, 100 kΩ und 1 MΩ. Ideal für vielseitige Schaltungen.
Stabile Leistung bei hohen Temperaturen Dank der Metallfilm-Technologie bieten diese Widerstände eine hohe Temperaturstabilität und geringe Temperaturkoeffizienten. Ideal für anspruchsvolle elektronische Anwendungen.
Präzise Toleranz von 1% für exakte Schaltungen Mit einer 1%-Toleranz und 1W Leistung eignen sich diese Widerstände besonders für präzise Strom- und Spannungsteiler in Messtechnik und Schaltungsentwicklung.
Standard-DIP-Bauform für einfache Montage Die DIP-Metallfilm-Farbring Bauform ermöglicht eine einfache Hand- und Maschinenbestückung. Ideal für Breadboards, PCBs und Prototypen.
Mehr
Weitere Preisinformationen 
Kundenbewertungen (26)
Spezifikationen
Übersicht
Laden
Das könnte Sie auch interessieren
Bewertungen | 4.8
 
 
26 Bewertungen
 
Alle von verifizierten Einkäufen
Materialhaltbarkeit : Hoch
50%
Haltbarkeit : Schnell
81%
Lötbarkeit : Schnell
81%
Alle Bewertungen (6) (1) (0)gut verpackt (5)schnelle lieferung (2)akzeptabel (2)zufriedenstellend (2)unvollständige bestellung (1)
5.0
5.0
5.0
5.0
5.0
1.0
Mehr anzeigen
Standardmäßig sortierenOriginalsprache anzeigen
Widerstand:0,13R
Ganz gut, obwohl ich das falsche Modell bestellt habe. Ich habe 1 Watt bestellt (und es auch erhalten), aber es hätte 0,25 Watt sein sollen. Mein Fehler. Der Lieferant hat es extrem sorgfältig verpackt und es kam unbeschädigt an. 10 Punkte.
D***r | 15 Juni 2026
 Hilfreich (0)   
Widerstand:680R
Schneller Versand, Produkt wie beschrieben, gut verpackt.
+1
AliExpress-Einkäufer | 07 Feb. 2026
 Hilfreich (0)   
Widerstand:68K
Es handelt sich tatsächlich um Widerstände. Ich werde nicht alle überprüfen, aber einer hat 1 Ohm, also wette ich, dass die anderen es auch sind.
AliExpress-Einkäufer | 17 Jan. 2026
 Hilfreich (0)   
Mehr anzeigen
Ähnliche Artikel
Previous
50 Stück 1/2 W 0,5 W 1 % 1 K 1 M 68R 75 82 91R 100 120 150R 680 200 220 240 270R 300 330R 470 Ω OHM DIP Metallfilm-Farbringwiderstand
1,59€
5
500+ verkauft
Kostenloser Versand ab 10€
100 Stück 1/4 W Metallschichtwiderstandselement 1 % 0,25 W 1 K 1,5 K 2,2 K 4,7 K 10 K 22 K 47 K 100 K 470 K 100 220 4K7 Ohm 5 Farbringwiderstände
1,39€
4.9
5.000+ verkauft
0,03€ sparen
Auf AliExpress meistverkauft
Werbeanzeige
300 Stück/600 Stück/820 Stück 1% Widerstands-Set 1/4W Metallfilm-Widerstände Kit 10Ohm ~1M Ohm 30 Werte Elektronik-Komponenten-Set
3,69€
4.9
5.000+ verkauft
Auf AliExpress meistverkauft
Kostenloser Versand ab 10€
Werbeanzeige
1/4W 1/2W 1W 2W 3W Widerstandsset Widerstand 1% 1/4W 1/2W 1W 2W 3W Metallfilm-Widerstände Kit Ohm Elektronische Komponenten Set
3,69€
4.8
1.000+ verkauft
0,21€ sparen
Auf AliExpress meistverkauft
Werbeanzeige
20PCS 1W Metallschichtwiderstand 1% Fünf-Farben-Ring-Leistungswiderstand 0,1~1M 2 4,7 10R 47 100 220 360 470 1K 2,2K 10K 22K 4,7K 100K Ohm
1,49€
4.9
5.000+ verkauft
0,05€ sparen
Auf AliExpress meistverkauft
Next
Spezifikationen
Hochbetriebenes Chemikalienunternehmen
Keine
Genauigkeit
1%
Typ
Metallschichtwiderstand
Ursprung
CN (Herkunft)
Zustand
Neu
Übersicht
Melden
Mehr anzeigen
Informationen zu Zusatzkosten
Bei von außerhalb der Europäischen Union gelieferten Artikeln fallen in Ihrem Land u. U. weitere MwSt.- und wenn anwendbar Zollgebühren an. Wenn AliExpress per Gesetz zur Erhebung der MwSt. verpflichtet ist, wird der Preis an der Kasse inklusive Mehrwertsteuer angezeigt. Für weitere Informationen zu diesen Kosten wenden Sie sich bitte an das Finanzamt bzw. die Zollbehörde Ihres Landes.
Verkauft durch HY Electronic Components Store. Logistik durch AliExpress.
Informationen zur Produktkonformität
Haftungsausschluss
Haftungsausschluss: Bilder und Produktinformationen auf dieser Seite können automatisch von KI übersetzt worden sein. Diese Übersetzungen werden nur zur Bequemlichkeit und im Ist-Zustand bereitgestellt und können Ungenauigkeiten oder Inkonsistenzen enthalten.
1,99€/Viel 
50Stück ; Preis inkl. MwSt. | Zölle werden an der Kasse berechnet  ; Zusätzlicher 6 % Rabatt
Widerstand: 51K ohm
 
Bearbeiten
Verkauft von
HY Electronic Components Store
(Händler)
 Kontaktieren
  
  
AliExpress-Verpflichtung
Pick-up points  
Kostenloser Versand über 10,00€  
Zustellung: Um Sep 11 - 16 
Kurierdienst:   DHL Paket   Hermes ,etc.  
Expresslieferung
 
1,00€ Coupon-Code für die verspätete Lieferung
 
Geld zurück bei defekt geliefertem Artikel
 
Geld zurück bei verlorenem Paket
 
Geld zurück bei Nichtlieferung in 40 Tagen
Rückgabe bis 90 Tage kostenlos
Sicherheit und Datenschutz persönliche Daten schützen
Sichere Zahlungen: Wir geben keine Ihrer personengebundenen Daten ohne Ihre Zustimmung an Dritte weiter.
Persönliche Angaben schützen: Wir schützen Ihre Privatsphäre und bewahren Ihre personengebundenen Daten sicher auf.
Menge
6665 verfügbar
Jetzt kaufenIn den Warenkorb
 Teilen
 14
  
HY Electronic Components Store
99.1% Positives Feedback | 166 Follower
 
Kontaktieren
Empfohlen von HY Electronic Components Store
1pcs Raspberry Pi Pico W Board RP2040 Dual-Core 264 KB ARM Low-Power-Mikrocomputer Hochleistungs-Cortex-M0+ Prozessor
3,59€
1
6 verkauft
Kostenloser Versand ab 10€
2 Stück 80V 10000µF 63V 10000µF 100V 10000µF JCCON 30/35mm Audio-Elektrolytkondensator High Fidelity Verstärker Niedriger ESR Kupferanschluss
8,99€
5
21 verkauft
Kostenloser Versand ab 10€
5er-Set 5*20mm 6*30mm Glas-Sicherungshalter mit 22AWG Kabel 250V 5X20MM Glas-Sicherungsrohr Sicherungsgehäuse 6x30mm
2,69€
5
86 verkauft
Kostenloser Versand ab 10€
10pcs Original Wago Verdrahtungsklemme 221-412 221-413 221-415 221-612 221-613 221-615 221-2411 221-2401 Verdrahtungsverbinder
5,59€
4.9
3.000+ verkauft
Auf AliExpress meistverkauft
Kostenloser Versand ab 10€
WXD3-13-2W 10K Ω 100/220/470/680 Ohm WXD3-13 2W Drahtgewickeltes Mehrgang-Potentiometer 1K 2,2K 4,7K 5,6K 6,8K 47K 100K Drehschalter
1,29€
5
58 verkauft
Kostenloser Versand ab 10€
1000PCS 1/4W Kohleschichtwiderstand 5% 1R 1M 10R 100R 220R 330R 1K 2.2K 3.3K 4.7 5.6k 6.8K 9.1 10K 22K 47K 100K 100 220 330 470 910 ohm
3,79€
5
29 verkauft
Kostenloser Versand ab 10€
Das könnte Sie auch interessieren
100 Stück 1/6 W Metallschichtwiderstände 1/8 W 1 % 0,125 W 10 100 200 220 330 470 Ohm 4,7 K 1 K 2,2 K 10 K 47 K 200 K 220 K 510 K 100 K 470 K 1 M Ohm
1,35€
5
2.000+ verkauft
0,03€ sparen
Auf AliExpress meistverkauft
Werbeanzeige
100 stücke 1/4W 1R ~ 22M 1% Metall film widerstand 100R 220R 1K 1,5 K 2,2 K 4,7 K 10K 22K 47K 100K 100 220 1K5 2K2 4K7 ohm widerstand
0,85€
0,92€
-8%
5
2.000+ verkauft
Individuell anpassbar
300/600 Stück 1 % Widerstandsset, Widerstand 1/4 W, Metallschichtwiderstände-Set, 10 Ohm ~ 1 M Ohm, 30 Werte, elektronische Komponenten-Kit
3,85€
4.7
2.000+ verkauft
Auf AliExpress meistverkauft
Kostenloser Versand ab 10€
100 Stück 470 Ohm 1/4 W 470R Metallschichtwiderstand 470 Ohm 0,25 W 1 % ROHS
1,59€
4.9
500+ verkauft
0,06€ sparen
Kostenloser Versand ab 10€
Werbeanzeige
20 Stück/Set 3W Metallfilm-Widerstände 1% 0,1R-2,2M 2,2 10 100 150 220 270 330 470 1K 2,2K 4,7K 10K 15K 22K 47K 100K 220K 470K 1M Ohm
2,35€
4.9
1.000+ verkauft
0,13€ sparen
Auf AliExpress meistverkauft
Werbeanzeige
600-teiliges Metallschichtwiderstands-Set, sortiertes Kit, 30 Werte, Metallschichtwiderstand, Widerstand 1/4 W, 1 Ohm-10 Mohm, 1 % Toleranz
2,69€
4.7
5.000+ verkauft
Jedes 2,55€, ≥ 2 Stücke
3,03€ sparen
Fonland 10 Stück/Set USA CVD Fokuslinse ZnSe Laserlinse Durchmesser 20 19,05 18 FL 38,1/50,8/63,5/76,2/101,6/127 für CO2-Schneidemaschine
111,69€
4.6
141 verkauft
11,01€ sparen
Kostenloser Versand ab 10€
Werbeanzeige
100 stücke 1/4W Metall film widerstand 1% 47K 51K 56K 62K 68K 75K 82K 91K 100K 110K 120K 130K 150K 160K 180K 200K 220K 240K 270K ohm
2,55€
4.9
182 verkauft
Kostenloser Versand ab 10€
Freies Schiff 100 stücke 1/4 W Metall Film Widerstand 1R--10M +-1% 10K Ohm 10K 4,7 karat 2,2 K 1K 100K 0,25 W 0R 3/4/5/6/7/8/9.1.2.3.4.5.6.7/R/K
2,05€
4.9
2.000+ verkauft
0,07€ sparen
Auf AliExpress meistverkauft
400/1500 Stück SMD Aluminium-Elektrolytkondensator-Set 24/36 Werte 1UF‑1000UF 6.3V‑50V mit Aufbewahrungsbox für elektronische DIY-Lötreparaturprojekte
48,39€
121,73€
-60%
Frühbucherangebot, nur noch 1 übrig
Kostenloser Versand
Werbeanzeige
1300PCS 1/2W 0,5W 1% 1R~3M Ohm 130Werte Metallschichtwiderstand Sortiment Kit
15,49€
4.7
107 verkauft
0,68€ sparen
Kostenloser Versand ab 10€
100pcs 1/4W Metall film widerstand 1R ~ 1M 100R 220R 330R 1K 1,5 K 2,2 K 3,3 K 4,7 K 10K 22K 47K 100K 100 220 330 1K5 2K2 3K3 4K7 ohm
1,25€
4.9
495 verkauft
Auf AliExpress meistverkauft
Kostenloser Versand ab 10€
Werbeanzeige
Hängelampen für die Heimdekoration, luxuriöser Kristall-Kronleuchter für das Wohnzimmer, Hängelampe für das Esszimmer, Deckenleuchte, Innenbeleuchtung
107,39€
5
8 verkauft
126,07€ sparen
Kostenloser Versand
Werbeanzeige
2600 Stück 130 Werte 1/6 W = 1/8 W 0,125 W 1 % Metallschichtwiderstände, sortiertes Paket-Set, Lot-Widerstände, Sortimentskits, feste Kondensatoren
9,29€
4.7
267 verkauft
Jedes 8,89€, ≥ 2 Stücke
5,45€ sparen
Werbeanzeige
20 Stück 1 W Metallschichtwiderstände 1 % 10 Ohm 47 100 200 220 470 510 Ohm 1 K 4,7 K 10 K 22 K 33 K 47 K 100 K 200 K 220 K 510 K 470 K 910 K 1 M Ohm
1,35€
4.9
4.000+ verkauft
0,03€ sparen
Auf AliExpress meistverkauft
Werbeanzeige
Rostentferner-Spray für Autoräder, schnell wirkender Rostlöser, Korrosionsschutz für Auspuffrohre, Fahrgestell, Metall, 1/3 Stück
11,49€
18,84€
-39%
4.8
221 verkauft
Werbeanzeige
1000 teile/los 1W Metall Film Widerstand 1% 1R ~ 1M 2,2 R 10R 33R 47R 100R 220R 1K 2,2K 10K 33K 47K 100K 330K 470K 0,1 0,22 150 470 ohm
20,59€
4.8
116 verkauft
2,04€ sparen
Kostenloser Versand
230 Stück 2 W 1 % Metallschichtwiderstände 22R Ohm-51R, 100R, 1K, 100K, 120K, 150K, 1M Ohm Widerstandspaket mit 23 Werte, je 10 Stück
6,89€
4.8
82 verkauft
Jedes 6,59€, ≥ 2 Stücke
9,28€ sparen
Werbeanzeige
Nordic wohnkultur Kronleuchter für esszimmer glanz anhänger lichter hängen lampen für decke Leuchte innen beleuchtung
189,69€
3.7
17 verkauft
155,2€ sparen
Kostenloser Versand
Werbeanzeige
150PCS 300PCS 1/4W 1/2W 1W 2W 3W Widerstand 1% Metall Film Widerstand Sortiment Kit Set 30 Arten Jeder 5/10PCS 1 ~ 750 1K ~ 820K Ohm
2,25€
4.9
500+ verkauft
Jedes 2,15€, ≥ 2 Stücke
1,11€ sparen
Werbeanzeige
1100 Stück 1/2 W Metallfilm-Widerstands-Set, 1 % 0,1 Ohm – 2,2 m, 110 Werte x 10 Stück 0,5 W Widerstandsset, Sortimentspackung
12,29€
4.7
322 verkauft
2,17€ sparen
Kostenloser Versand
150/180/620-teiliges Polyester-Film-Kondensator-Set 100V, verschiedene Werte 1nF-100nF, 2A102J 2A471J 2A222J Sortiment für Elektronikschaltungsreparaturen, DIY-Lötarbeiten 2028
18,29€
78,58€
-76%
Frühbucherangebot, nur noch 1 übrig
Kostenloser Versand
Werbeanzeige
10 Stück 3w 1% 0.1R 0.36R 0.56 0.75R 3.9R 1K 1.8K 6.8K 9.1K 10K 91K 110 120K 1M 1.5M 2.2M 68R 75 82 91R 100 120 150R 680 200 220 240 270R 300 330R 470 680 910Ω ohm Dip-Metallfilm-Farbring widerstand
1,79€
20 verkauft
0,02€ sparen
Kostenloser Versand ab 10€
130 Werte 1/4 W 1/6 W 1/2 W 1 W 2 W 1 % Metallschichtwiderstände, sortiertes Paket, Kit-Set, Lot-Widerstände, Sortimentskits, fester Widerstand 10 K
12,79€
4.8
109 verkauft
Jedes 12,19€, ≥ 2 Stücke
5,75€ sparen
Werbeanzeige
121 Werte 1/4 Watt 1 % hochpräzise Metallschichtwiderstände 1 100 220 330 470 1K 4,7K 10K 15K 20K 22K 33K 47K Ohm 1/4W Widerstand
2,39€
5
1.000+ verkauft
0,09€ sparen
Auf AliExpress meistverkauft
Werbeanzeige
100 Stück 1/4w 0,25 w 1% 1K 0.1R 1.5 M 68R 75 82 91R 100 120 150R 680 200 220 240 270R 300 330R 470 Ω Ohm Dip-Metallfilm-Farbring widerstand
1,35€
4.8
1.000+ verkauft
Auf AliExpress meistverkauft
Kostenloser Versand ab 10€
10 Stück 3W Präzisions-Metallschichtwiderstände 1% 3W 10 47 100 200 220 470 510 Ohm 1K 22K 4,7K 10K 47K 100k 200k 220k 510k 470k 1M Ohm
1,45€
4.8
2.000+ verkauft
0,04€ sparen
Auf AliExpress meistverkauft
Werbeanzeige
100 Stück 330 Ohm 1/4 W 330R Metallschichtwiderstand 330 Ohm 0,25 W 1 % ROHS
1,59€
4.9
900+ verkauft
0,06€ sparen
Auf AliExpress meistverkauft
Werbeanzeige
2600 Stück 130 Werte 1/4 W Widerstandssatz von 1 Ohm auf 3 M Ohm 1/4 Watt 1 % Toleranz Metallfilmwiderstände Sortiment
12,19€
4.9
290 verkauft
13,75€ sparen
Kostenloser Versand ab 10€
1 W 1 % Widerstands-Sortiment-Set, 35 Werte, 350 Stück 1 Watt Metallschichtwiderstände, 1 Ohm bis 1 M Ohm, elektronisches Widerständepaket
26,99€
5 verkauft
Kostenloser Versand
Werbeanzeige
128TB Tragbare Externe SSD-Festplatte Kleines Gehäuse Große Leistung Grundlegender Tages-Speicher für PC MAC
20,79€
29,7€
-30%
4 verkauft
Frühbucherangebot, nur noch 4997 übrig
Kostenloser Versand
Werbeanzeige
1/4W 1/2W 1W 2W 3W Widerstandsset 1% Metallschichtwiderstands-Sortimentskit 1K~820K 0,1R~750R 10K
2,29€
4.9
2.000+ verkauft
2,29€ sparen
Kostenloser Versand ab 10€
Werbeanzeige
Snvi Widerstands-Set 1/4W 1% Metallfilm-Widerstände Set 300 Stück 600 Stück 820 Stück 2600 Stück 30 41 130 Werte Elektronische Komponenten
2,59€
4.8
900+ verkauft
0,18€ sparen
Kostenloser Versand ab 10€
Werbeanzeige
2TB Tragbare Solid-State-Festplatte Typ-C USB 3.1 Schnelle Schnittstelle Geeignet für Multigeräte-Datenspeicherung in Laptops/PCs
13,99€
5
14 verkauft
16,42€ sparen
Kostenloser Versand
Werbeanzeige
300/600 stücke 1/4w Metall film widerstand 30 Werte Widerstands kit 10r-1m 0,25 w 1% Widerstände eingestellt
1,29€
4.5
127 verkauft
10 stücke 3362P serie widerstand 101 201 501 102 202 502 103 Trimpo Trimmer Potentiometer 3362 500R 1K 2K 5K 10K 20K 50K 100K
1,05€
4.8
500+ verkauft
0,01€ sparen
Auf AliExpress meistverkauft
8TB tragbares Solid-State-Laufwerk, 32TB externes SSD mit großer Kapazität, USB3.1 Plug-and-Play, geeignet für Laptops/MAC/PC
17,19€
5
3 verkauft
9,67€ sparen
Werbeanzeige
1/4 W 1/8 W 1/2 W 1 W 2 W Metallschichtwiderstandssatz 130 Werte 0,125 W 0,25 W 0,5 W 1 % Widerstandssortiment, sortierte Setbox
13,99€
4.9
340 verkauft
13,99€ sparen
Kostenloser Versand ab 10€
300-2600 Stück 1/4W Widerstandskit 1% Metallfilm-Widerstände 0,25W 10Ω~1MΩ / 1Ω~3MΩ Widerstandsbox für DIY-Elektronik & Schaltkreisreparatur
2,65€
4.8
61 verkauft
Jedes 2,49€, ≥ 2 Stücke
2,87€ sparen
Schnelle Lieferung 1,6 Tonnen Mini-Bagger Kleiner Bagger CE Raupenbagger Hydraulischer Mini-Bagger Maßgefertigter 1-Tonnen Mini-Bagger
1.087,69€
5
87 verkauft
3.444,35€ sparen
Individuell anpassbar
Werbeanzeige
50 Stück Kohle film widerstände 1/2w 5% 100r 1,5 r1k 2,2 k 4,7 k k 10k 22k 47k 1 k5 2 k2 4 k7 Ohm neuer Widerstand 1r ~ 1m
1,25€
2,52€
-50%
4.9
5.000+ verkauft
Kostenloser Versand ab 10€
300PCS 150PCS 1/2W 1W 3W 2W Widerstand 1% Metall Film Widerstand Sortiment Kit Set 30 Arten Jeder 5/10PCS 1K ~ 820K 1R ~ 750R Ohm
3,59€
5
115 verkauft
0,09€ sparen
Kostenloser Versand ab 10€
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

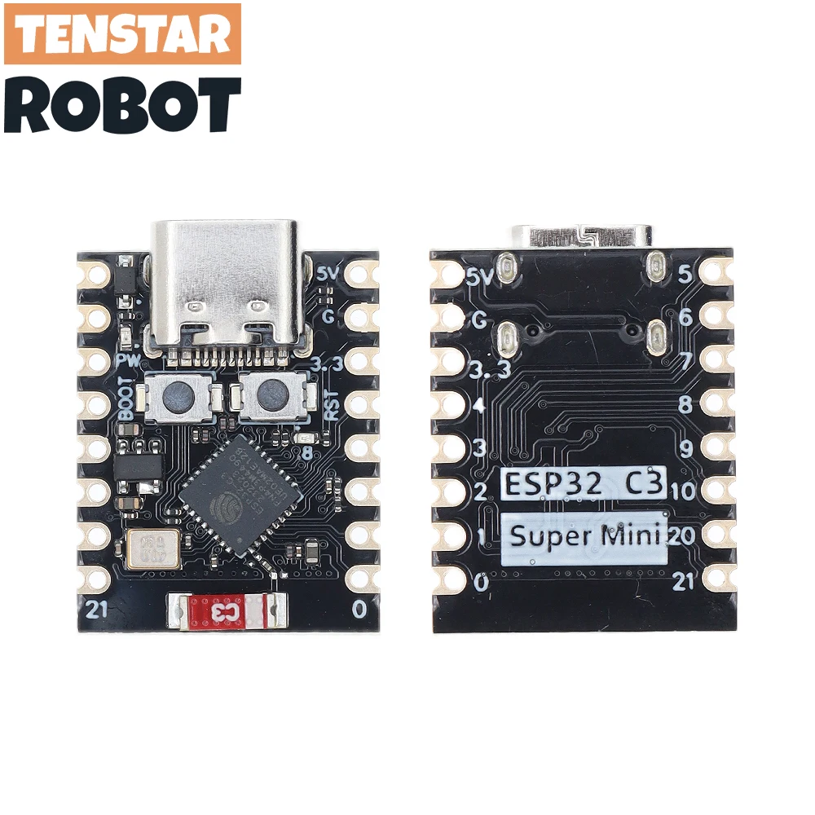
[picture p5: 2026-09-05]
reference/aliexpress-1005005967641936/gallery-05.webp

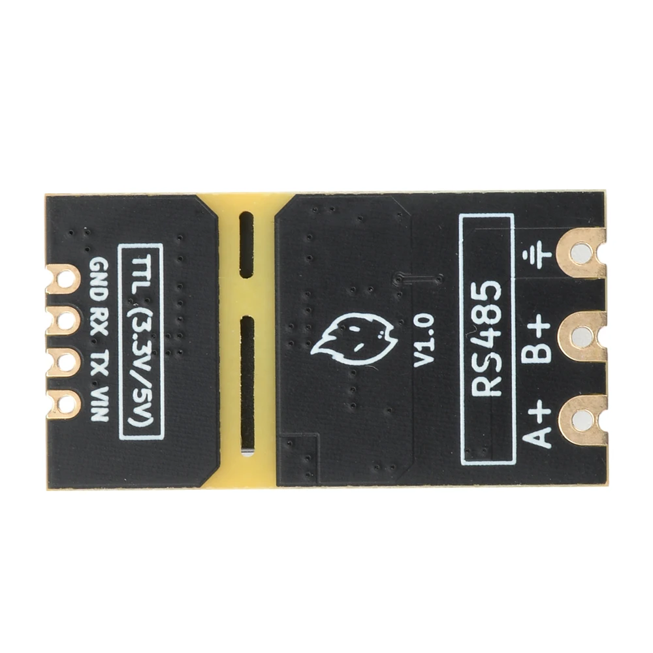
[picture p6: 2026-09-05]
reference/aliexpress-1005010178764203/gallery-05.webp

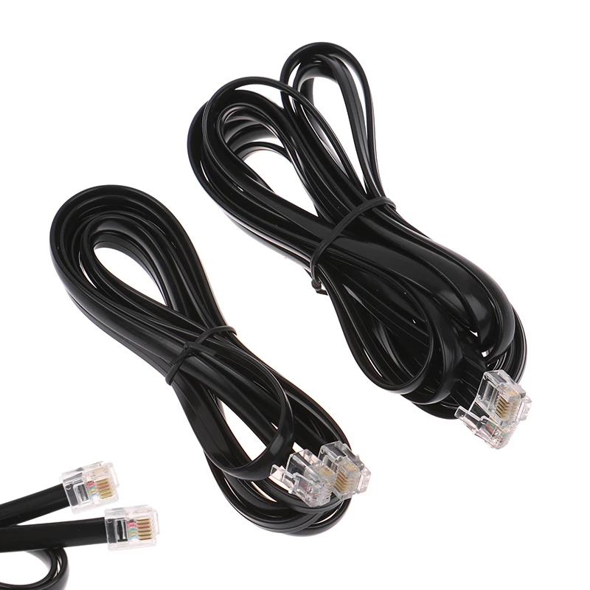
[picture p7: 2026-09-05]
reference/aliexpress-1005005913976427/gallery-02.webp

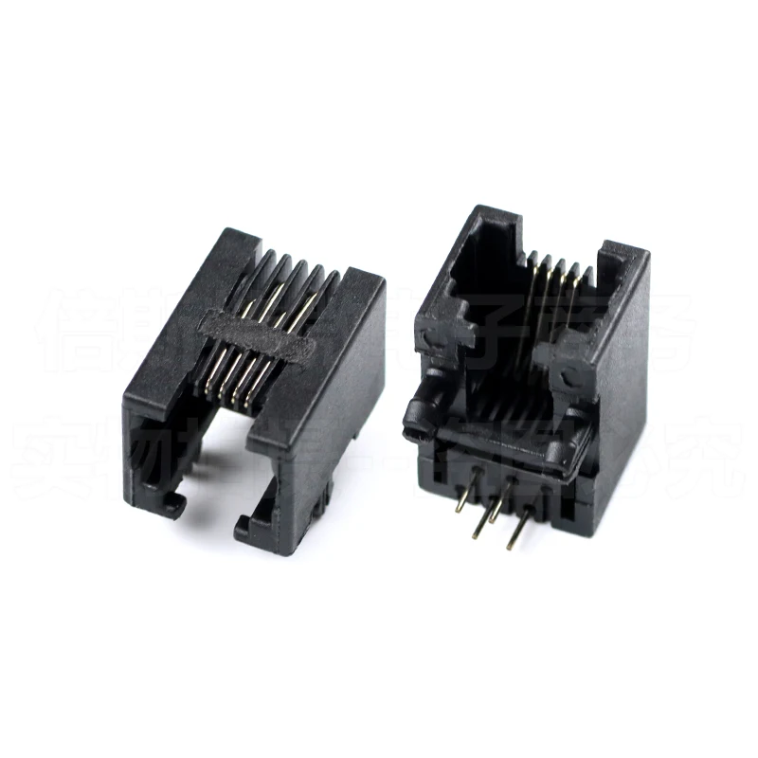
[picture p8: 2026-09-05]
reference/aliexpress-1005003078110991/gallery-03.webp

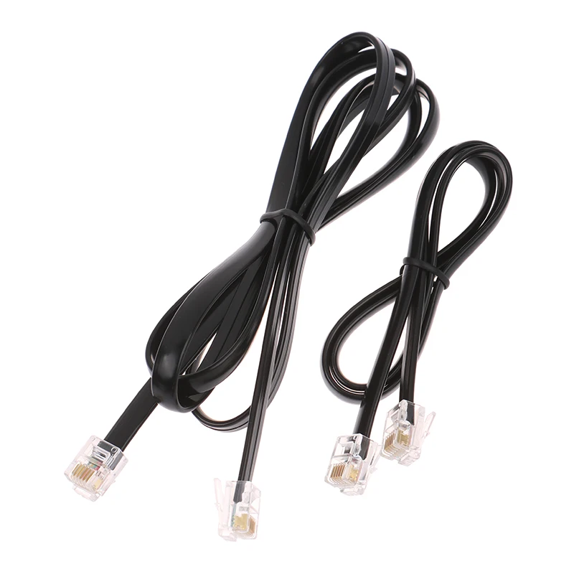
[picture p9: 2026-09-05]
reference/aliexpress-1005005913976427/gallery-03.webp

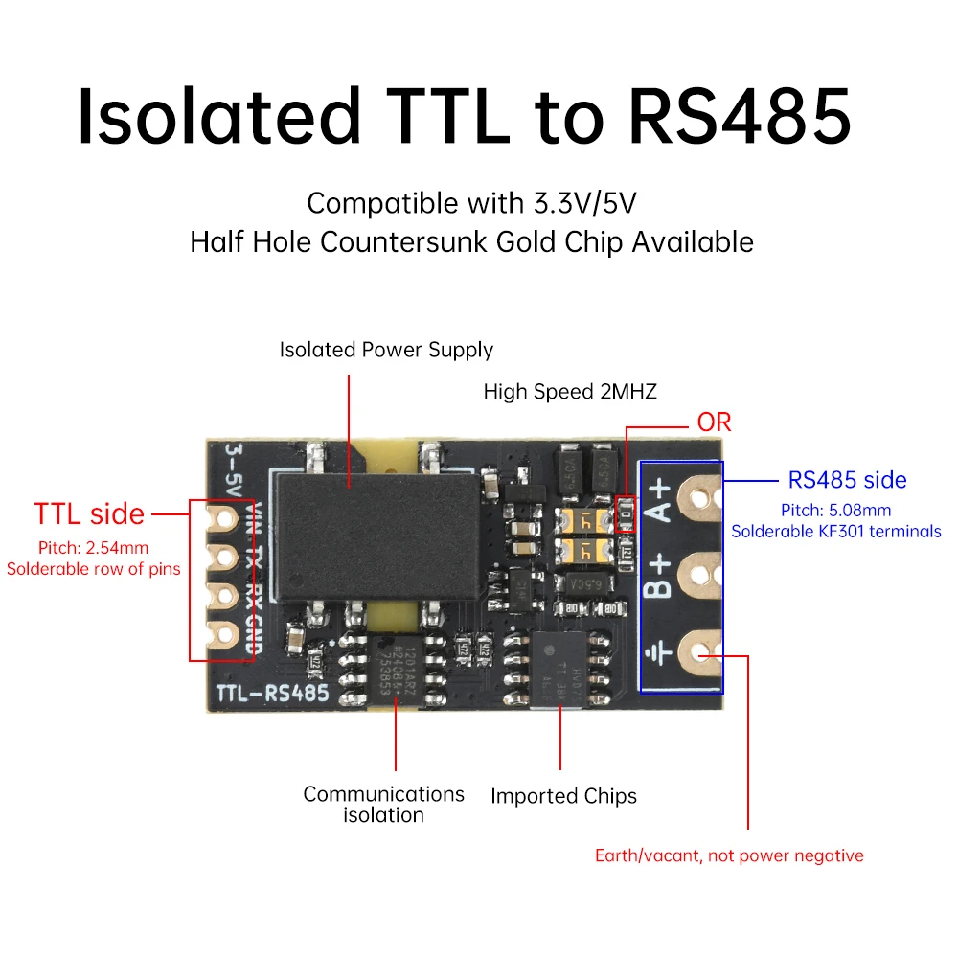
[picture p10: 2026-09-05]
reference/aliexpress-1005010178764203/gallery-02.webp

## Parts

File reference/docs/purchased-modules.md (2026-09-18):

# Purchased modules and supporting parts

The information below comes from vendor pages, product images, and linked datasheets. Measurements of the delivered samples take precedence before schematic and PCB approval.

## ESP32-C3 Super Mini

- AliExpress: <https://www.aliexpress.com/item/1005005967641936.html>
- Vendor description: TENSTAR ROBOT ESP32-C3 Super Mini
- Form factor: 16 pins, eight per side, 2.54 mm pitch
- Common reference dimensions: 22.52 × 18 mm
- USB-C, BOOT and RESET buttons, ceramic antenna
- ESP32-C3 with 4 MB flash according to the reference document
- The blue onboard LED is connected to GPIO8 on the common form factor

Typical pin order with USB-C at the top:

| Left side, top to bottom | Right side, top to bottom |
|---|---|
| 5V | GPIO5 |
| GND | GPIO6 |
| 3V3 | GPIO7 |
| GPIO4 | GPIO8 |
| GPIO3 | GPIO9 |
| GPIO2 | GPIO10 |
| GPIO1 | GPIO20 |
| GPIO0 | GPIO21 |

The schematic wires GPIO21 to U2's `TX` pad and GPIO20 to its `RX` pad. Because those names are the module's own, ESPHome has to be configured the other way round: `tx_pin: GPIO20`, `rx_pin: GPIO21`.

Open checks:

1. Measure outer dimensions, header spacing, and pin labels on the delivered board.
2. Test GPIO20 and GPIO21 as UART at 57600 baud, even parity, and one stop bit.
3. Measure current during boot, Wi-Fi association, and normal operation.
4. Verify the behavior of the 5V pin and USB VBUS. Community documentation warns against simultaneous external and USB power.
5. Test Wi-Fi reception in the intended enclosure and keep the antenna region clear on the carrier PCB.

Local documents:

- [Official ESP32-C3 datasheet](../datasheets/esp32-c3-espressif-v2.4.pdf)
- [Community Super Mini form-factor datasheet](../datasheets/esp32-c3-supermini-community.pdf)
- [Vendor archive](../aliexpress-1005005967641936/)

## LM2596 buck converter module

- AliExpress: <https://www.aliexpress.com/item/1005006362601789.html>
- Product marking: `LM2596 DC-DC HW-411`
- Regulator marking: `LM2596S ADJ`
- Connections: IN+, IN-, OUT+, OUT-
- Adjustable output through trimmer `103`
- Approximate vendor dimensions: 45 × 22 × 13 mm
- Visible capacitors: input 100 µF/50 V, output 220 µF/35 V

The vendor's 46 V input claim is not adopted as a design limit. The TI datasheet specifies 40 V as the recommended maximum input and 45 V as the IC absolute maximum. The HCP bus is approximately 25 V, but the low-cost module's population, layout, capacitors, and protection still require separate evaluation.

Intended setup:

1. Power the loose module from approximately 25 V without the ESP32.
2. Adjust the output to 5.0 V.
3. Measure the output under load and during power-on and power-off.
4. Connect the ESP32 only after those checks pass.

Open checks:

- Measure outer dimensions and mounting holes.
- Measure quiescent current, startup time, and temperature at the actual load.
- Exclude startup overshoot.
- Evaluate reverse-polarity, transient, and trimmer-failure behavior.
- Retain a disconnectable `BUS_PWR` link so USB and external 5 V cannot be applied simultaneously.

Local documents:

- [TI LM2596 datasheet](../datasheets/lm2596-ti-snvs124g.pdf)
- [Vendor archive](../aliexpress-1005006362601789/)

## Isolated TTL-to-RS485 module

- AliExpress: <https://www.aliexpress.com/item/1005010178764203.html>
- Vendor description: isolated 3.3 V/5 V TTL-to-RS485 module with automatic direction control
- Approximate dimensions: 34 × 18 × 9 mm
- TTL side at 2.54 mm pitch: VIN, TX, RX, GND
- Those TTL names are from the module's point of view, confirmed by measurement on the assembled board: `TX` is the receiver output that drives the MCU, `RX` is the driver input. Wiring MCU TX to the pad marked `TX` leaves the RS485 driver permanently off.
- Bus side at 5.08 mm pitch: A+, B- or B+ in some images, plus a third terminal
- No DE or RE line; direction changes automatically
- Vendor claims: up to 2 Mbit/s, galvanic isolation, TVS, fuse, and integrated 120 Ω termination

The product images do not identify the transceiver reliably enough to establish its permitted bus voltage. One image labels the third bus-side terminal as earth or unused, explicitly not supply ground. Leave it open until labels and continuity are checked on the delivered module.

The preliminary schematic powers the module at 3.3 V to avoid a possible 5 V level at ESP32 RX. Before hardware release, verify reliable 3.3 V operation and sufficient capacity on the Super Mini 3.3 V regulator.

Acceptance checks on the delivered module:

1. Photograph and verify the labels on both sides.
2. Measure DC resistance between A and B with power removed.
3. The module has measured 120 Ω between A and B when unpowered. Do not add another termination resistor to the carrier PCB.
4. Measure the RX output logic level at the selected supply voltage.
5. Verify transmit direction switching and reception at 57600 baud with even parity.
6. Measure galvanic isolation between TTL ground and the bus side.
7. Verify A/B labeling with a known frame or oscilloscope.

Local document: [vendor archive](../aliexpress-1005010178764203/)

## 120 Ω resistor

- AliExpress: <https://www.aliexpress.com/item/1005007375826162.html>
- Purchased variant: 120 Ω, 1 W, 1%, axial metal film
- Use: loose spare and measurement part, not fitted to the carrier PCB

The RS485 module reportedly includes 120 Ω termination. Adding a parallel resistor would produce approximately 60 Ω and load the bus unnecessarily. The PCB therefore has neither the resistor nor a footprint for it.

Local archive: [AliExpress 1005007375826162](../aliexpress-1005007375826162/)

## 6P6C cable

- AliExpress: <https://www.aliexpress.com/item/1005005913976427.html>
- Vendor description: RJ11/RJ12 6P6C plug-to-plug straight-through cable, which suits the `straight` board and not the `cross` one
- Listed lengths: 0.5 m, 1 m, 2 m, 3 m, and 5 m; the purchased length is not yet recorded

Product images are inconsistent and some show only four visible conductors. Verify every cable before connection:

1. Both plugs have six contacts.
2. All six conductors have continuity.
3. No adjacent contacts are shorted.
4. Contact 1 maps to contact 6, 2 to 5, and 3 to 4.

Point 4 holds for the `cross` board, whose J1 follows the pinout in the ESPHome
documentation while the opener's jack is mirrored against it. The `straight` board mirrors
J1 instead and wants 1 to 1 through 6 to 6. Pairing the wrong cable with either board puts
+25 V on the adapter's ground. The purchased cable is straight-through and was rebuilt into
a reversed one by hand for the `cross` board built here.

Local archive: [AliExpress 1005005913976427](../aliexpress-1005005913976427/)

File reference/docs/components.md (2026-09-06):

# Components

This document records specific purchased parts. A generic chip name does not replace the exact module variant or its measured footprint.

## Status values

- `Candidate`: not ordered or definitively selected
- `Selected`: definitively selected, but not delivered or measured
- `On hand`: purchased, but not electrically and mechanically verified
- `Measured`: pinout and dimensions confirmed on the physical part
- `Approved`: accepted for the schematic and PCB

## Bill of materials

| Ref. | Function | Specific part | Status | Documentation | Open verification |
|---|---|---|---|---|---|
| J1 | HCP2 jack | 95001-style modular jack, vendor option `6P6C` unshielded, AliExpress 1005003078110991 | Selected | [Jack documentation](connector-rj12.md), [vendor archive](../aliexpress-1005003078110991/) | Confirm dimensions, hole pattern, contact order, and mechanical fit on the sample |
| W1 | HCP2 cable | 6P6C plug-to-plug cable, AliExpress 1005005913976427 | On hand | [Module note](purchased-modules.md#6p6c-cable), [vendor archive](../aliexpress-1005005913976427/) | Record length, confirm six contacts, and measure straight-through continuity |
| U1 | Controller | TENSTAR ROBOT ESP32-C3 Super Mini, AliExpress 1005005967641936 | On hand | [Module note](purchased-modules.md#esp32-c3-super-mini), [official datasheet](../datasheets/esp32-c3-espressif-v2.4.pdf), [form-factor reference](../datasheets/esp32-c3-supermini-community.pdf) | Verify form factor, pinout, UART, current draw, USB VBUS, and Wi-Fi on the sample |
| PS1 | 25 V to 5 V | Adjustable LM2596 DC-DC HW-411, AliExpress 1005006362601789 | On hand | [Module note](purchased-modules.md#lm2596-buck-converter-module), [TI datasheet](../datasheets/lm2596-ti-snvs124g.pdf) | Set to 5.0 V; measure dimensions, load behavior, startup time, and overshoot |
| U2 | RS485 | Isolated 3.3 V/5 V TTL-to-RS485 module with automatic direction control, AliExpress 1005010178764203 | On hand | [Module note](purchased-modules.md#isolated-ttl-to-rs485-module), [vendor archive](../aliexpress-1005010178764203/) | Verify pinout, 3.3 V operation, isolation, A/B labeling, and integrated termination |

## Open checks

See [TODO.md](../../TODO.md).

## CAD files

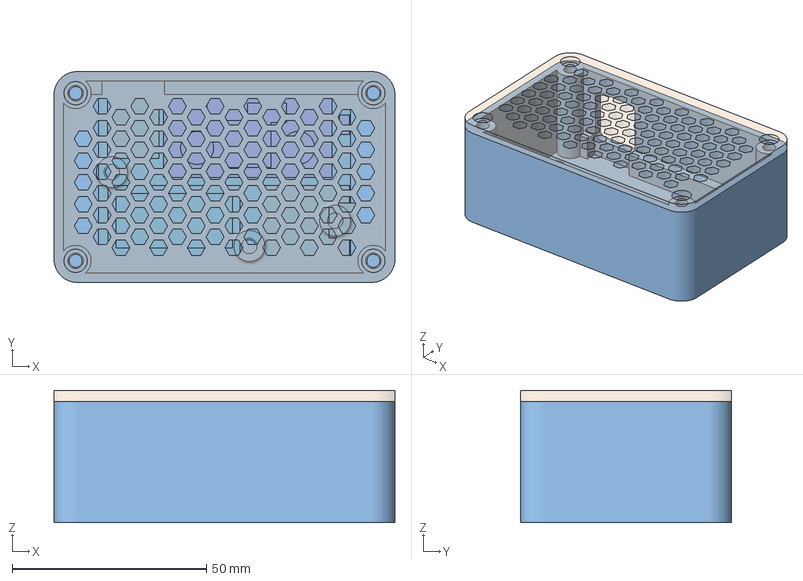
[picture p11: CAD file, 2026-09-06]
enclosure/preview.3mf
87.8 x 54.3 x 34.0 mm
bottom
pcb
J1 HCP2 6P6C
PS1 LM2596 HW-411
U2 Isolated RS485
U1 ESP32-C3 Super Mini
JP1 BUS_PWR
6P6C plug
top

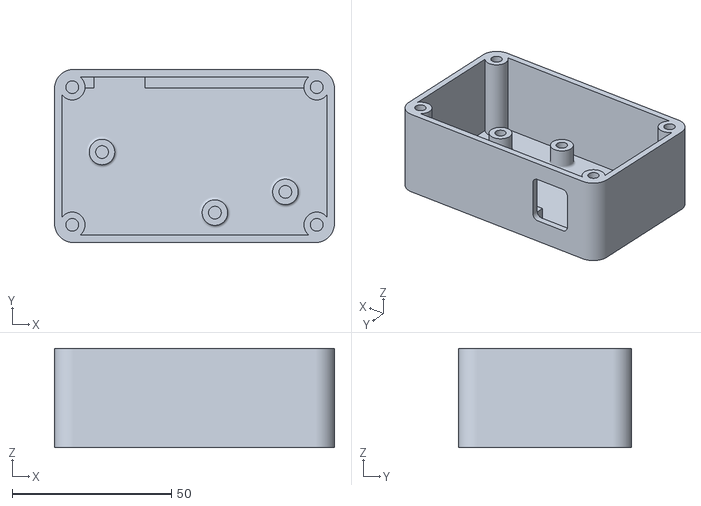
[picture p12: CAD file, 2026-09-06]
enclosure/bottom.stl
87.8 x 54.3 x 31.2

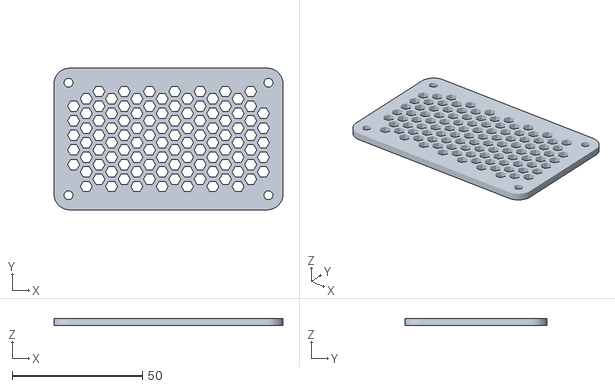
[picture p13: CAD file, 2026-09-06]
enclosure/top.stl
87.8 x 54.3 x 2.80

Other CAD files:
enclosure/preview.stl

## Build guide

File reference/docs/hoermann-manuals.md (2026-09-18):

# Hörmann manual analysis

The manuals supplied with this project remain unchanged under [`reference/manuals/`](../manuals/). They are the primary sources for the specific ProMatic 4 opener and its accessories.

## ProMatic 4 installation, operation, and maintenance

- File: [garagentor_4511178_ProMatic_4_DE.pdf](../manuals/garagentor_4511178_ProMatic_4_DE.pdf)
- Document number: `4511178 B0`
- Edition: `18-2022 / RE`
- Language: German
- Title: Garage door operator, instructions for fitting, operation, and maintenance

Relevant sections:

- Section 5.5 describes DIL switch C for internal lighting, BUS, and pre-warning.
- Section 5.10 describes the BUS scan.
- A BUS scan removes and rediscovers connected accessories.
- HOR 1-HCP and UAP 1-HCP are listed as Series 4 accessories.
- Electrical work and mains-voltage areas are reserved for qualified personnel.

## ProMatic 4 functional description and accessories

- File: [garagentor_4553098_B0_ProMatic_4_Funktionsbeschreibung_Zubehoer.pdf](../manuals/garagentor_4553098_B0_ProMatic_4_Funktionsbeschreibung_Zubehoer.pdf)
- Document number: `4553098 B0`
- Edition: `21-2022`
- Title: Garage door operator, functional description and accessories
- Languages: multilingual; German begins on page 2

Relevant sections:

- Section 3.9 identifies the BUS socket for accessories with special functions.
- BUS scan procedure: connect participants, move DIL switch H from OFF to ON, then back to OFF.
- A scan removes and rediscovers BUS accessories.
- Section 4 sets a 350 mA maximum combined accessory load on the opener.
- Series 3 accessories require the HAP 1 HCP adapter.
- HOR 1-HCP and UAP 1-HCP are explicitly listed as HCP accessories.

The 350 mA value is a combined accessory limit, not the automatic allowance for this adapter alone. Measure the actual startup current of the ESP32, RS485 module, and LM2596 during a BUS scan and keep it comfortably below that limit.

## HOR1-HCP option relay

- File: [garagentor_hoermann-optionsrelais-hor1-hcp-anleitung.pdf](../manuals/garagentor_hoermann-optionsrelais-hor1-hcp-anleitung.pdf)
- Document number: `TR30A117`
- Edition: `07.2019`
- Product: `HOR1-HCP`

Relevant sections:

- The wiring diagram specifies Series 4 and a maximum BUS cable length of 10 m.
- The BUS participant connects through the opener's BUS interface.
- Status LED: flashing green means not registered, solid green means registered, and three red flashes indicate a BUS scan.
- Relay ratings are 2.5 A at 30 V DC or 500 W at 250 V AC. These values do not apply to the adapter electronics.

## Consolidated design limits

| Limit | Source | Design consequence |
|---|---|---|
| Series 4 only | ProMatic and HOR1-HCP manuals, ESPHome | No compatibility claim for Series 3 |
| 350 mA maximum combined accessories | Functional description, section 4 | Measure adapter startup and operating current |
| 10 m maximum BUS cable | HOR1-HCP wiring diagram | Record the installed cable length |
| Accessories are rediscovered during scans | Both ProMatic manuals | Connect the adapter before scanning and keep it able to boot during the scan |
| No work while mains is connected | Safety sections | Disconnect the mains plug and any emergency battery before installation |

The exact HCP2 contact assignment and UART parameters come from the ESPHome HCP documentation. The Hörmann manuals confirm the BUS connection, Series 4 scope, and scan procedure, but the reviewed passages do not provide a reliable six-pin signal assignment.

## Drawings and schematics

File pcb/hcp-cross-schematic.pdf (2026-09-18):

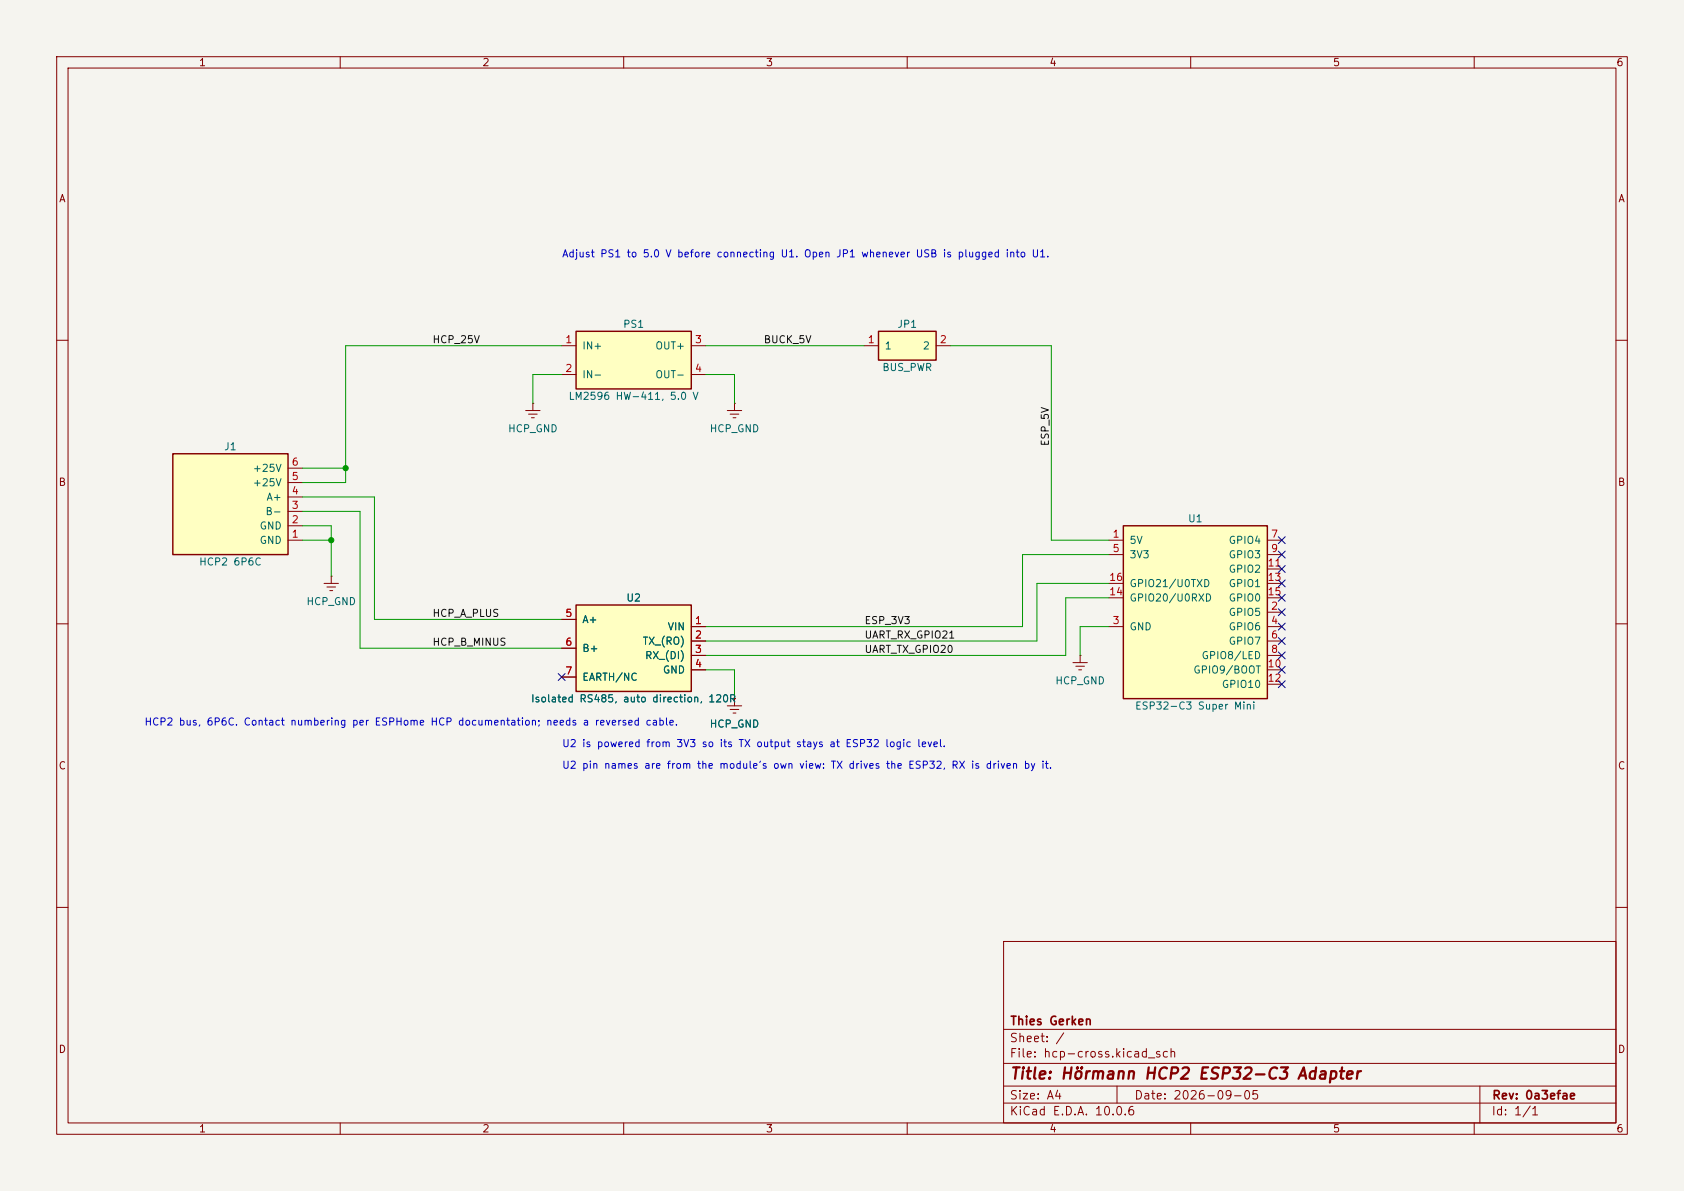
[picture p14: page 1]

Adjust PS1 to 5.0 V before connecting U1. Open JP1 whenever USB is plugged into U1. U2

Size: A4 | Rev: 0a3efae
KiCad E.D.A. 10.0.6 | Id: 1/1

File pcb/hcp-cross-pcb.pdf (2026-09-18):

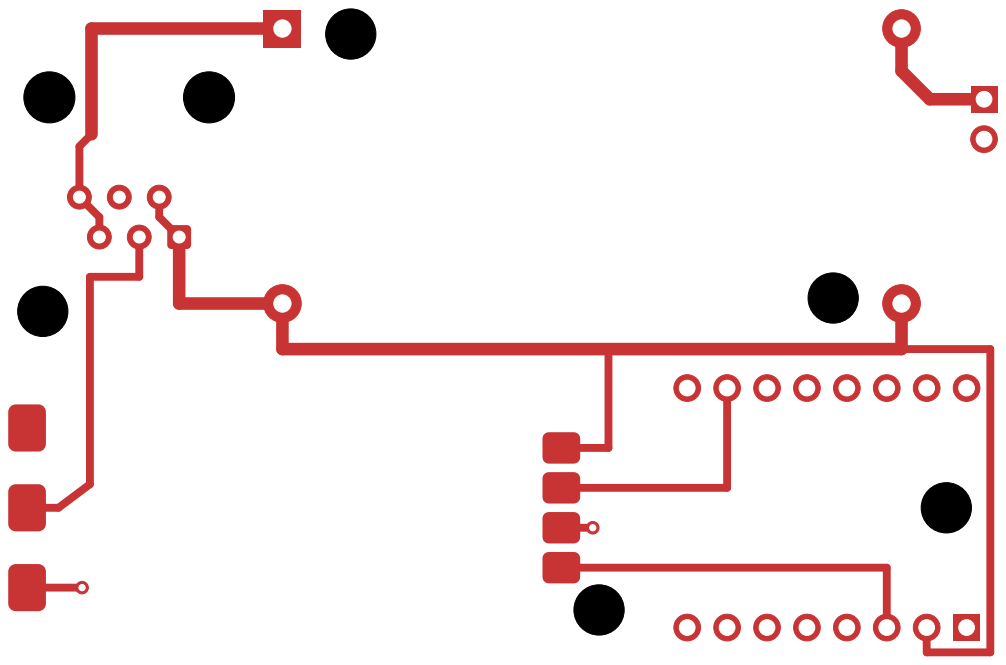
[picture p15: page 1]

Size: A4 | Rev:
KiCad E.D.A. 10.0.6 | Id: 1/5

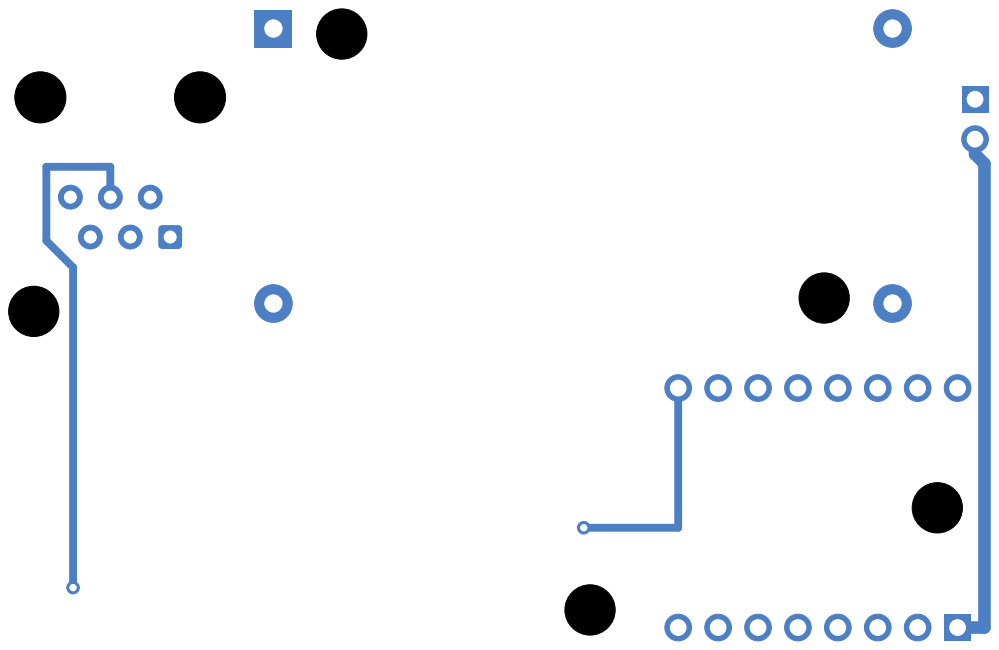
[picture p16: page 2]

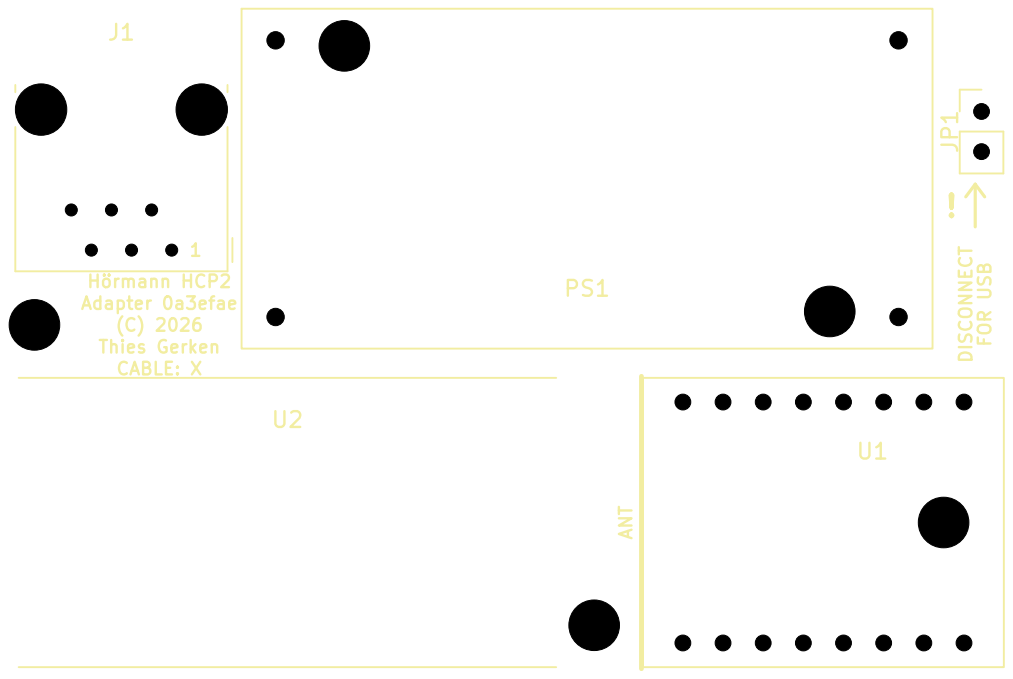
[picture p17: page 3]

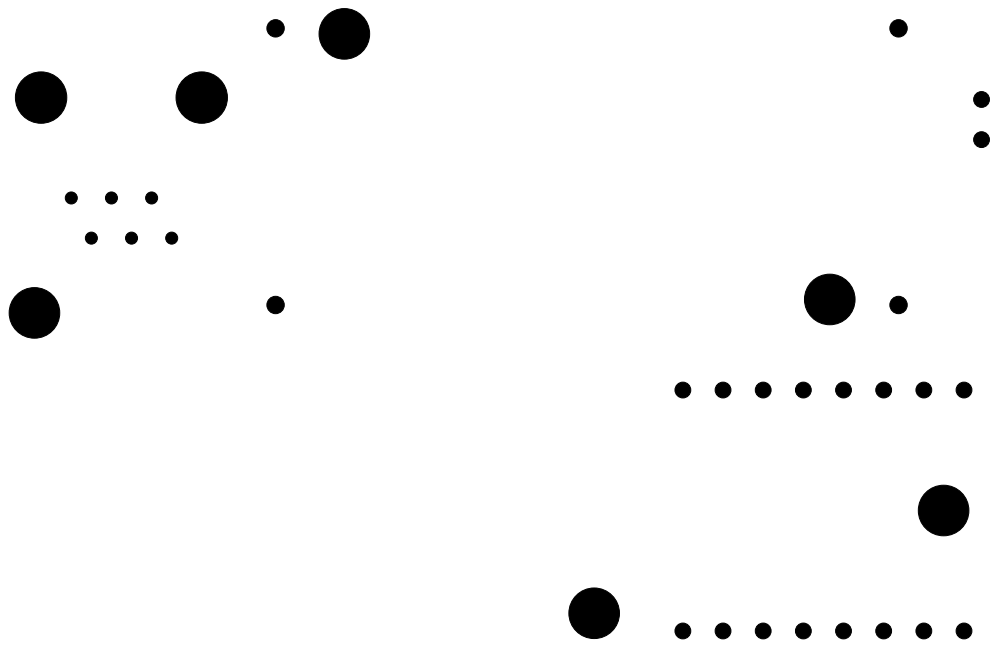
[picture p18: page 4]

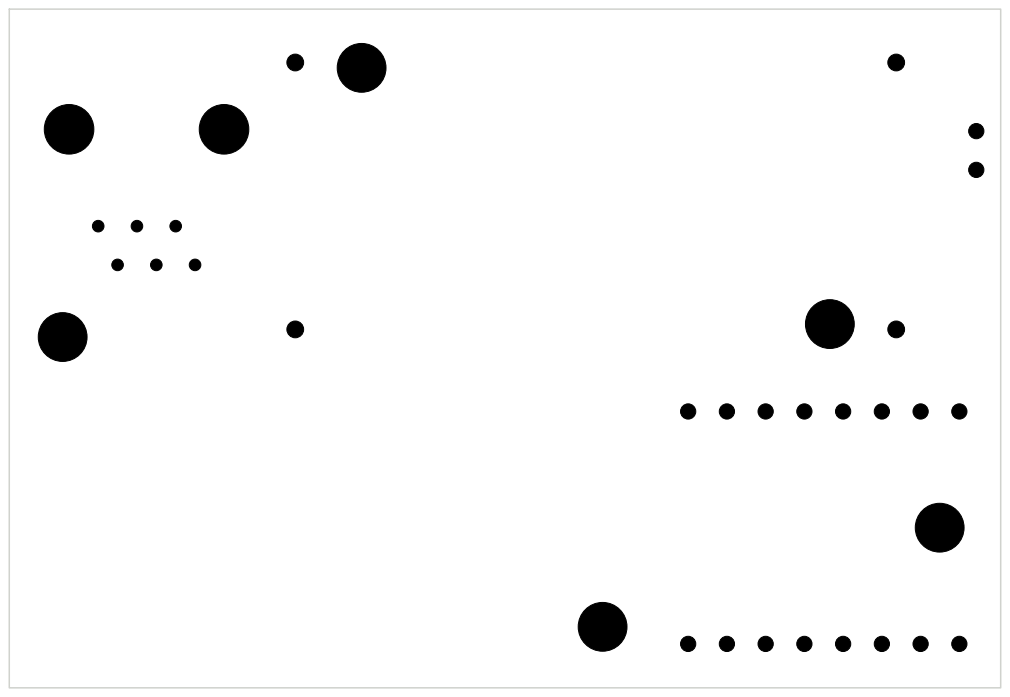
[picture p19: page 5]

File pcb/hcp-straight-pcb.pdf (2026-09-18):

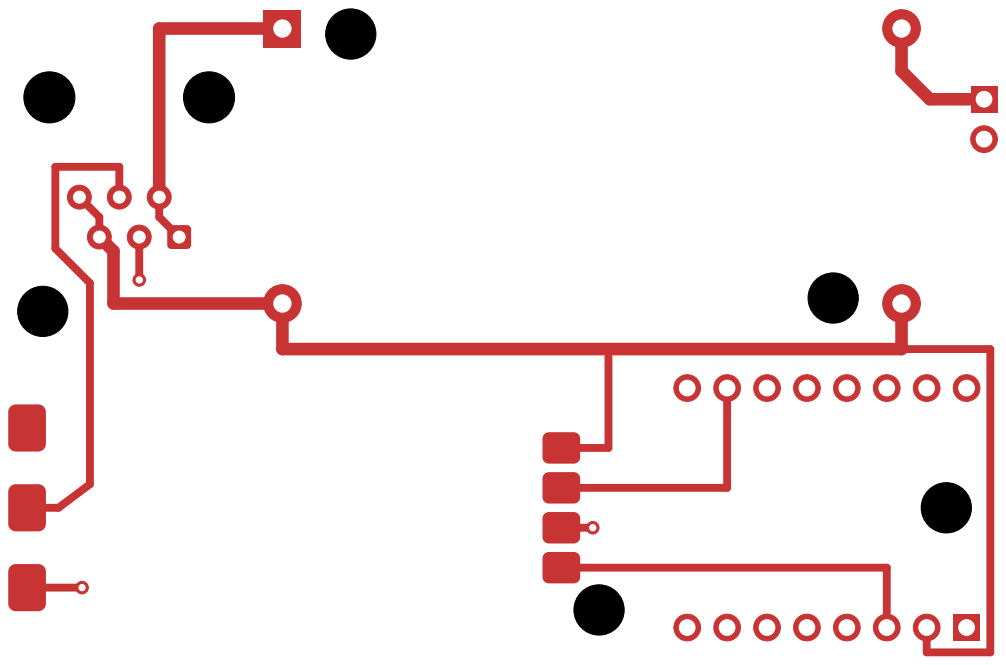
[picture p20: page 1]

Size: A4 | Rev:
KiCad E.D.A. 10.0.6 | Id: 1/5

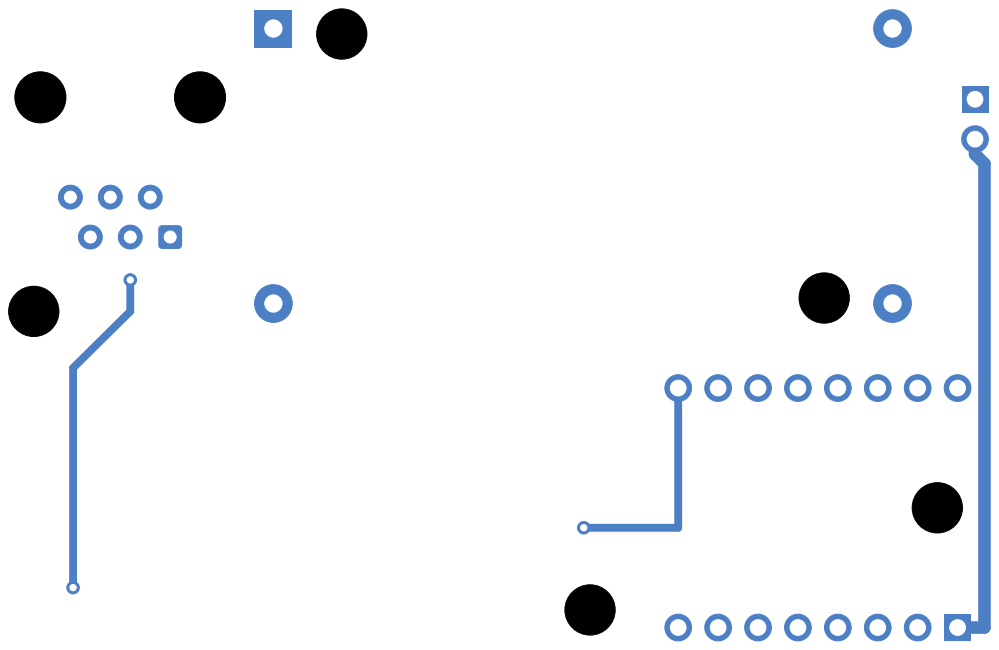
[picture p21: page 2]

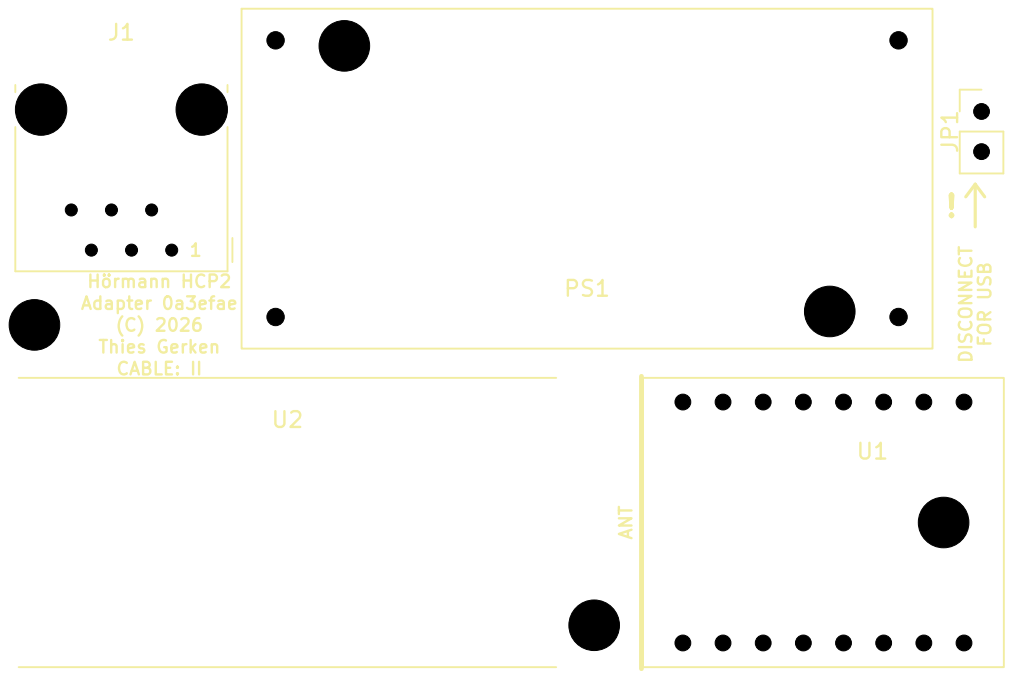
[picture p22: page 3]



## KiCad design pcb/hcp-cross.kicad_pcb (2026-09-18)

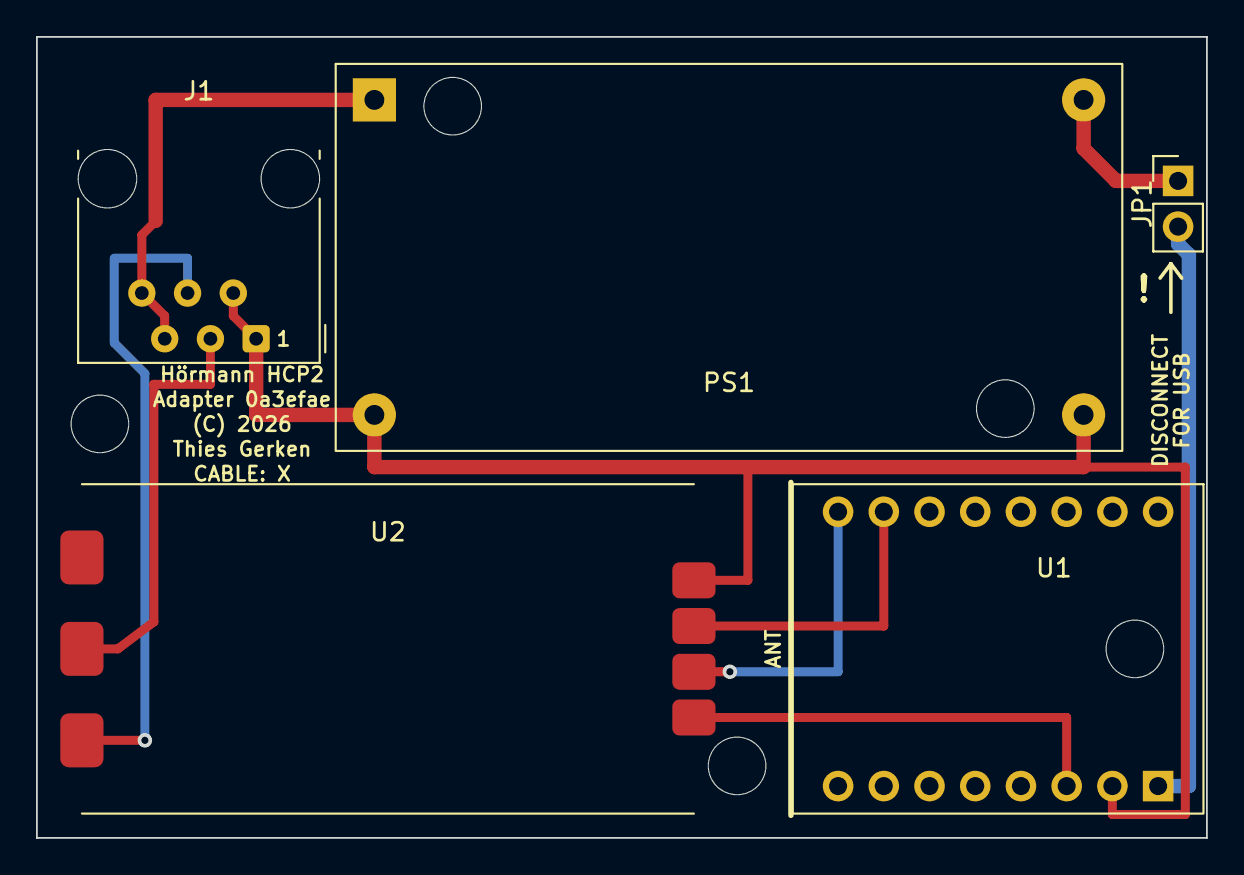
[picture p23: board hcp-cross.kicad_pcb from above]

Board: 2 copper layers, 65.0 x 44.5 mm, 8 parts (0 on the bottom side), 9 nets.

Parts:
H1, H3, H4: M3; MountingHole_3.2mm_NoCourtyard
J1: HCP2 6P6C; RJ12_Amphenol_54601-x06_Horizontal
JP1: BUS_PWR; PinHeader_1x02_P2.54mm_Vertical
PS1: LM2596 HW-411; LM2596_HW-411
U1: ESP32-C3 Super Mini; ESP32-C3_SuperMini
U2: Isolated RS485; RS485_Isolated_34x18

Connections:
BUCK_5V: JP1.1, PS1.3
ESP_3V3: U1.5, U2.1
ESP_5V: JP1.2, U1.1
HCP_25V: J1.5, J1.6, PS1.1
HCP_A_PLUS: J1.4, U2.5
HCP_B_MINUS: J1.3, U2.6
HCP_GND: J1.1, J1.2, PS1.2, PS1.4, U1.3, U2.4
UART_RX_GPIO21: U1.16, U2.2
UART_TX_GPIO20: U1.14, U2.3

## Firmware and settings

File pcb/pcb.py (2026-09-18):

"""Generate the carrier PCB from the footprints in HCP.pretty and the net model in design.py.

Placement and routing use explicit coordinates. Run this file to rebuild the
KiCad project beside the generator, run DRC, and render previews.
"""
import json
import math
import re
import shutil
import subprocess
import sys
import uuid
from pathlib import Path

from design import VARIANTS, connections, git_version, selected_variant

SOURCE_DIR = Path(__file__).parent
LIBRARY_DIR = SOURCE_DIR / "HCP.pretty"
OUTPUT_DIR = SOURCE_DIR
# The enclosure imports this module for the placement and the footprints, so the variant
# must not be read from that script's command line.
VARIANT = selected_variant() if __name__ == "__main__" else VARIANTS[0]
EXPECTED_CONNECTIONS = connections(VARIANT)
STEM = f"hcp-{VARIANT}"
BOARD_PATH = OUTPUT_DIR / f"{STEM}.kicad_pcb"
PROJECT_PATH = OUTPUT_DIR / f"{STEM}.kicad_pro"
FP_LIB_TABLE_PATH = OUTPUT_DIR / "fp-lib-table"
PREVIEW_TOP_PATH = OUTPUT_DIR / f"{STEM}-pcb-top.png"
PREVIEW_BOTTOM_PATH = OUTPUT_DIR / f"{STEM}-pcb-bottom.png"
PDF_PATH = OUTPUT_DIR / f"{STEM}-pcb.pdf"
GERBER_DIR = OUTPUT_DIR / "gerbers"
GERBER_ZIP = OUTPUT_DIR / f"{STEM}-gerbers.zip"
VERSION = git_version()
DRC_PATH = OUTPUT_DIR / f"{STEM}-drc.json"

BOARD_W, BOARD_H = 65.0, 44.5
# Board-relative design coordinates are shifted by this origin when written, so the
# board sits centred on the A4 sheet used by the layer PDF.
ORIGIN = (116.0, 68.0)
SIGNAL, POWER = 0.5, 0.8

NET_NAMES = tuple(EXPECTED_CONNECTIONS)
NET_IDS = {name: index for index, name in enumerate(NET_NAMES, start=1)}
PIN_NETS = {
    pin_id: net_name
    for net_name, pin_ids in EXPECTED_CONNECTIONS.items()
    for pin_id in pin_ids
}

FOOTPRINTS = {
    "J1": "RJ12_Amphenol_54601-x06_Horizontal",
    "PS1": "LM2596_HW-411",
    "JP1": "PinHeader_1x02_P2.54mm_Vertical",
    "U1": "ESP32-C3_SuperMini",
    "U2": "RS485_Isolated_34x18",
    "H1": "MountingHole_3.2mm_NoCourtyard",
    "H3": "MountingHole_3.2mm_NoCourtyard",
    "H4": "MountingHole_3.2mm_NoCourtyard",
}

# (x, y, rotation). J1 (Amphenol 54601 geometry, latch down) opens towards the top edge, PS1 IN side towards J1, U2 bus side
# on the left edge under J1, U1 with its USB end flush with the right board edge so a
# cable can be plugged in while mounted. Roughly 2 mm between module outlines and
# 1.5 mm to the board edge elsewhere.
PLACEMENT = {
    "J1": (12.18, 16.77, 180),
    "PS1": (38.45, 12.25, 0),
    "JP1": (63.4, 8.0, 0),
    "U2": (19.5, 34.0, 180),
    "U1": (53.4, 34.0, 270),
    # M3 enclosure holes in the free spots: below J1, between U2 and U1, and under the
    # socketed U1 where the screw head fits beneath the module. Each needs 3.6 mm of
    # solder-free underside around it for the enclosure standoffs; the top-right corner
    # has no room for that and rests on the enclosure ledge instead.
    "H1": (3.5, 21.5, 0),
    "H3": (38.9, 40.5, 0),
    "H4": (61.0, 34.0, 0),
}
REFERENCE_POSITIONS = {
    "J1": (9.0, 3.0),
    "PS1": (38.45, 19.2),
    "JP1": (61.4, 9.27, 90),
    "U2": (19.5, 27.5),
    "U1": (56.5, 29.5),
}
VALUES = {
    "J1": "HCP2 6P6C",
    "PS1": "LM2596 HW-411",
    "JP1": "BUS_PWR",
    "U1": "ESP32-C3 Super Mini",
    "U2": "Isolated RS485",
    "H1": "M3",
    "H3": "M3",
    "H4": "M3",
}

# Points are absolute board coordinates. Pad centres are computed from the footprints
# and checked against the route vertices in check_routes().
#
# J1 carries the two bus pairs on mirrored contacts between the variants, so every route
# that touches it is variant specific. The contacts sit on two staggered rows, which is
# why the mirror cannot simply be reflected in x.
J1_ROUTES = {
    "cross": (
        ("HCP_25V", "F.Cu", SIGNAL, ((7.1, 16.77), (7.1, 15.5), (5.83, 14.23), (5.83, 11.0), (6.6, 10.23))),
        ("HCP_25V", "F.Cu", POWER, ((6.6, 10.23), (6.6, 3.5), (18.75, 3.5))),
        ("HCP_GND", "F.Cu", SIGNAL, ((10.91, 14.23), (10.91, 15.5), (12.18, 16.77))),
        ("HCP_GND", "F.Cu", POWER, ((12.18, 16.77), (12.18, 21.0), (18.75, 21.0))),
        ("HCP_B_MINUS", "F.Cu", SIGNAL, ((9.64, 16.77), (9.64, 19.3), (6.5, 19.3), (6.5, 32.5), (4.5, 34.0), (2.5, 34.0))),
        ("HCP_A_PLUS", "B.Cu", SIGNAL, ((8.37, 14.23), (8.37, 12.3), (4.3, 12.3), (4.3, 17.0), (6.0, 18.7), (6.0, 39.08))),
        ("HCP_A_PLUS", "F.Cu", SIGNAL, ((6.0, 39.08), (2.5, 39.08))),
    ),
    # Supply and ground swap ends of the contact row, so the supply now leaves on the
    # right under the jack body and ground takes the short way down to PS1. A+ ends up on
    # the wrong side of ground and changes layer to get past it.
    "straight": (
        ("HCP_25V", "F.Cu", SIGNAL, ((10.91, 14.23), (10.91, 15.5), (12.18, 16.77))),
        ("HCP_25V", "F.Cu", POWER, ((10.91, 14.23), (10.91, 3.5), (18.75, 3.5))),
        ("HCP_GND", "F.Cu", SIGNAL, ((7.1, 16.77), (7.1, 15.5), (5.83, 14.23))),
        ("HCP_GND", "F.Cu", POWER, ((7.1, 16.77), (8.0, 17.67), (8.0, 21.0), (18.75, 21.0))),
        ("HCP_B_MINUS", "F.Cu", SIGNAL, ((8.37, 14.23), (8.37, 12.3), (4.3, 12.3), (4.3, 17.5), (6.5, 19.7), (6.5, 32.5), (4.5, 34.0), (2.5, 34.0))),
        ("HCP_A_PLUS", "F.Cu", SIGNAL, ((9.64, 16.77), (9.64, 19.5))),
        ("HCP_A_PLUS", "B.Cu", SIGNAL, ((9.64, 19.5), (9.64, 21.5), (6.0, 25.1), (6.0, 39.08))),
        ("HCP_A_PLUS", "F.Cu", SIGNAL, ((6.0, 39.08), (2.5, 39.08))),
    ),
}
SHARED_ROUTES = (
    ("HCP_GND", "F.Cu", POWER, ((18.75, 21.0), (18.75, 23.9), (58.15, 23.9), (58.15, 21.0))),
    ("HCP_GND", "F.Cu", SIGNAL, ((58.15, 23.9), (63.8, 23.9), (63.8, 43.2), (59.75, 43.2), (59.75, 41.62))),
    ("HCP_GND", "F.Cu", SIGNAL, ((39.5, 23.9), (39.5, 30.19), (36.5, 30.19))),
    ("BUCK_5V", "F.Cu", POWER, ((58.15, 3.5), (58.15, 6.2), (59.95, 8.0), (63.4, 8.0))),
    ("ESP_5V", "B.Cu", POWER, ((63.4, 10.54), (63.4, 11.5), (64.0, 12.1), (64.0, 41.62), (62.29, 41.62))),
    ("ESP_3V3", "F.Cu", SIGNAL, ((57.21, 41.62), (57.21, 37.81), (36.5, 37.81))),
    ("UART_TX_GPIO20", "F.Cu", SIGNAL, ((47.05, 26.38), (47.05, 32.73), (36.5, 32.73))),
    ("UART_RX_GPIO21", "B.Cu", SIGNAL, ((44.51, 26.38), (44.51, 35.27), (38.5, 35.27))),
    ("UART_RX_GPIO21", "F.Cu", SIGNAL, ((38.5, 35.27), (36.5, 35.27))),
)
ROUTES = SHARED_ROUTES + J1_ROUTES[VARIANT]
VIAS = (
    ("UART_RX_GPIO21", 38.5, 35.27),
    ("HCP_A_PLUS", 6.0, 39.08),
) + ((("HCP_A_PLUS", 9.64, 19.5),) if VARIANT == "straight" else ())
# Arrow from the USB warning up to JP1.
SILK_LINES = (
    ((63.0, 15.3), (63.0, 12.6)),
    ((63.0, 12.6), (62.4, 13.4)),
    ((63.0, 12.6), (63.6, 13.4)),
)
SILK_TEXTS = (
    # Five lines between the silkscreen of J1 above and U2 below, which leaves room for
    # 1.38 mm of line pitch and no more.
    ("Hörmann HCP2", 11.4, 18.75, 0, 0.8, "F.SilkS"),
    (f"Adapter {VERSION}", 11.4, 20.13, 0, 0.8, "F.SilkS"),
    ("(C) 2026", 11.4, 21.51, 0, 0.8, "F.SilkS"),
    ("Thies Gerken", 11.4, 22.89, 0, 0.8, "F.SilkS"),
    ("1", 13.7, 16.77, 0, 0.8, "F.SilkS"),
    ("!", 61.5, 14.0, 0, 1.4, "F.SilkS"),
    ("DISCONNECT", 62.4, 20.2, 90, 0.8, "F.SilkS"),
    ("FOR USB", 63.6, 20.2, 90, 0.8, "F.SilkS"),
    ("ANT", 40.9, 34.0, 90, 0.8, "F.SilkS"),
    # The two boards look identical once assembled, and plugging the wrong cable into
    # either puts +25 V on the adapter's ground.
    (f"CABLE: {'X' if VARIANT == 'cross' else 'II'}", 11.4, 24.27, 0, 0.8, "F.SilkS"),
)


def object_uuid(name):
    return uuid.uuid5(uuid.NAMESPACE_URL, f"hoermann-pcb:{name}")


def sheet(x, y):
    return round(x + ORIGIN[0], 2), round(y + ORIGIN[1], 2)


def sexp_block(text, start):
    depth = 0
    quoted = False
    for index in range(start, len(text)):
        character = text[index]
        if character == '"' and text[index - 1] != "\\":
            quoted = not quoted
        elif not quoted and character == "(":
            depth += 1
        elif not quoted and character == ")":
            depth -= 1
            if depth == 0:
                return index + 1
    raise RuntimeError("Unterminated S-expression")


def rotate(x, y, degrees):
    # KiCad footprint rotation: positive is counter-clockwise on screen with y pointing down.
    angle = math.radians(degrees)
    return x * math.cos(angle) + y * math.sin(angle), -x * math.sin(angle) + y * math.cos(angle)


def pad_positions(footprint_text, x, y, rotation):
    positions = {}
    for match in re.finditer(r'\(pad "([^"]+)" \w+ \w+\s*\(at (-?[\d.]+) (-?[\d.]+)', footprint_text):
        number, px, py = match.group(1), float(match.group(2)), float(match.group(3))
        if number:
            dx, dy = rotate(px, py, rotation)
            positions[number] = (round(x + dx, 2), round(y + dy, 2))
    return positions


def place_footprint(ref):
    name = FOOTPRINTS[ref]
    text = (LIBRARY_DIR / f"{name}.kicad_mod").read_text()
    text = re.sub(r'^\s*\((version|generator|generator_version) [^\n]*\n', "", text, flags=re.MULTILINE)
    text = text.replace(f'(footprint "{name}"', f'(footprint "HCP:{name}"', 1)
    # The same library footprint is placed several times, so its item uuids must be made unique.
    text = re.sub(r'\(uuid "([^"]+)"\)', lambda m: f'(uuid "{object_uuid(f"{ref}-{m.group(1)}")}")', text)
    x, y, rotation = PLACEMENT[ref]
    sx, sy = sheet(x, y)
    text = text.replace('(layer "F.Cu")', f'(layer "F.Cu")\n  (uuid "{object_uuid(ref)}")\n  (at {sx} {sy} {rotation})', 1)
    text = re.sub(r'\(property "Reference" "[^"]*"', f'(property "Reference" "{ref}"', text, count=1)
    text = re.sub(r'\(property "Value" "[^"]*"', f'(property "Value" "{VALUES[ref]}"', text, count=1)
    if ref in REFERENCE_POSITIONS:
        # Property positions are footprint-relative; convert the absolute target back.
        rx, ry, *angle = REFERENCE_POSITIONS[ref]
        lx, ly = rotate(rx - x, ry - y, -rotation)
        text = re.sub(
            r'(\(property "Reference" "[^"]*"\s*\(at )[^)]*\)',
            lambda m: f"{m.group(1)}{lx:.2f} {ly:.2f} {angle[0] if angle else 0})",
            text,
            count=1,
        )

    def add_net(match):
        number = match.group(1)
        net_name = PIN_NETS.get(f"{ref}.{number}")
        end = sexp_block(text, match.start())
        block = text[match.start():end]
        if rotation:
            # Pad angles are stored absolute in board files, so rotated footprints
            # need the footprint angle on every pad to still match their library copy.
            block = re.sub(r"\(at (-?[\d.]+) (-?[\d.]+)\)", rf"(at \1 \2 {rotation})", block, count=1)
        if net_name:
            block = block[:-1] + f' (net {NET_IDS[net_name]} "{net_name}"))'
        return block

    result = ""
    cursor = 0
    for match in re.finditer(r'\(pad "([^"]*)"', text):
        if match.start() < cursor:
            continue
        end = sexp_block(text, match.start())
        result += text[cursor:match.start()] + add_net(match)
        cursor = end
    result += text[cursor:]
    return "  " + result.replace("\n", "\n  ").rstrip() + "\n", pad_positions(text, x, y, rotation)


def check_routes(pads):
    """Every net must touch each of its pads with a route vertex."""
    endpoints = {}
    for net_name, _, _, points in ROUTES:
        endpoints.setdefault(net_name, set()).update(points)
    for net_name, pin_ids in EXPECTED_CONNECTIONS.items():
        for pin_id in pin_ids:
            ref, number = pin_id.split(".")
            position = pads[ref][number]
            if position not in endpoints.get(net_name, ()):
                raise RuntimeError(f"{net_name}: no route ends on {pin_id} at {position}")


def segments(net_name, layer, width, points, index):
    result = ""
    for segment_index, (start, end) in enumerate(zip(points, points[1:])):
        start, end = sheet(*start), sheet(*end)
        result += (
            f'  (segment (start {start[0]} {start[1]}) (end {end[0]} {end[1]}) '
            f'(width {width}) (layer "{layer}") (net {NET_IDS[net_name]}) '
            f'(uuid "{object_uuid(f"segment-{index}-{segment_index}")}"))\n'
        )
    return result


def write_project():
    OUTPUT_DIR.mkdir(exist_ok=True)
    # H1 deliberately sits under the socketed ESP32, so that DRC check is switched off.
    PROJECT_PATH.write_text(json.dumps({
        "board": {"design_settings": {"rule_severities": {"npth_inside_courtyard": "ignore"}}},
        "meta": {"filename": PROJECT_PATH.name, "version": 3},
    }, indent=2) + "\n")
    FP_LIB_TABLE_PATH.write_text(
        "(fp_lib_table\n  (version 7)\n"
        '  (lib (name "HCP") (type "KiCad") (uri "${KIPRJMOD}/HCP.pretty") (options "") (descr "Project footprints"))\n'
        ")\n"
    )


def build_board():
    board = (
        '(kicad_pcb\n  (version 20241229)\n  (generator "pcbnew")\n  (generator_version "9.0")\n'
        "  (general (thickness 1.6) (legacy_teardrops no))\n  (paper \"A4\")\n"
        '  (layers\n    (0 "F.Cu" signal)\n    (2 "B.Cu" signal)\n'
        '    (9 "F.Adhes" user "F.Adhesive")\n    (11 "B.Adhes" user "B.Adhesive")\n'
        '    (13 "F.Paste" user)\n    (15 "B.Paste" user)\n'
        '    (5 "F.SilkS" user "F.Silkscreen")\n    (7 "B.SilkS" user "B.Silkscreen")\n'
        '    (1 "F.Mask" user)\n    (3 "B.Mask" user)\n'
        '    (17 "Dwgs.User" user "User.Drawings")\n    (19 "Cmts.User" user "User.Comments")\n'
        '    (21 "Eco1.User" user "User.Eco1")\n    (23 "Eco2.User" user "User.Eco2")\n'
        '    (25 "Edge.Cuts" user)\n    (27 "Margin" user)\n'
        '    (31 "F.CrtYd" user "F.Courtyard")\n    (29 "B.CrtYd" user "B.Courtyard")\n'
        '    (35 "F.Fab" user)\n    (33 "B.Fab" user)\n  )\n'
        "  (setup (pad_to_mask_clearance 0) (allow_soldermask_bridges_in_footprints no))\n"
        '  (net 0 "")\n'
    )
    for name, net_id in NET_IDS.items():
        board += f'  (net {net_id} "{name}")\n'

    pads = {}
    for ref in FOOTPRINTS:
        text, positions = place_footprint(ref)
        board += text
        pads[ref] = positions
    check_routes(pads)

    for index, route in enumerate(ROUTES):
        board += segments(*route, index)
    for index, (net_name, x, y) in enumerate(VIAS):
        x, y = sheet(x, y)
        board += (
            f'  (via (at {x} {y}) (size 0.8) (drill 0.4) (layers "F.Cu" "B.Cu") '
            f'(net {NET_IDS[net_name]}) (uuid "{object_uuid(f"via-{index}")}"))\n'
        )

    board += (
        f'  (gr_rect (start {ORIGIN[0]} {ORIGIN[1]}) (end {ORIGIN[0] + BOARD_W} {ORIGIN[1] + BOARD_H}) (stroke (width 0.1) (type default)) '
        f'(fill none) (layer "Edge.Cuts") (uuid "{object_uuid("board-outline")}"))\n'
    )
    for index, (start, end) in enumerate(SILK_LINES):
        start, end = sheet(*start), sheet(*end)
        board += (
            f'  (gr_line (start {start[0]} {start[1]}) (end {end[0]} {end[1]}) '
            f'(stroke (width 0.2) (type default)) (layer "F.SilkS") (uuid "{object_uuid(f"line-{index}")}"))\n'
        )
    for index, (text, x, y, rotation, size, layer) in enumerate(SILK_TEXTS):
        x, y = sheet(x, y)
        mirror = " (justify mirror)" if layer.startswith("B.") else ""
        board += (
            f'  (gr_text "{text}" (at {x} {y} {rotation}) (layer "{layer}") '
            f'(uuid "{object_uuid(f"text-{index}")}") '
            f"(effects (font (size {size} {size}) (thickness {max(0.15, round(size * 0.18, 2))})){mirror}))\n"
        )
    board += "  (embedded_fonts no)\n)\n"
    BOARD_PATH.write_text(board)


def kicad_cli():
    found = shutil.which("kicad-cli") or "/Applications/KiCad/KiCad.app/Contents/MacOS/kicad-cli"
    if not Path(found).is_file():
        raise RuntimeError("kicad-cli is required")
    return found


def run_drc():
    subprocess.run(
        [kicad_cli(), "pcb", "drc", "--format", "json", "--severity-all",
         "--output", str(DRC_PATH), str(BOARD_PATH)],
        check=True,
    )
    report = json.loads(DRC_PATH.read_text())
    problems = [v for v in report["violations"] if v["severity"] == "error"]
    problems += report["unconnected_items"]
    for item in problems + [v for v in report["violations"] if v["severity"] == "warning"]:
        print(f'{item["severity"]}: {item["type"]}: {item["description"]}', file=sys.stderr)
    if problems:
        raise SystemExit(f"DRC failed with {len(problems)} error(s)")


def render_previews():
    for side, path in (("top", PREVIEW_TOP_PATH), ("bottom", PREVIEW_BOTTOM_PATH)):
        subprocess.run(
            [kicad_cli(), "pcb", "render", "--output", str(path), "--width", "1600",
             "--height", "1100", "--side", side, "--quality", "high", str(BOARD_PATH)],
            check=True,
        )
    subprocess.run(
        [kicad_cli(), "pcb", "export", "pdf", "--output", str(PDF_PATH),
         "--layers", "F.Cu,B.Cu,F.SilkS,B.SilkS,Edge.Cuts", "--mode-multipage",
         "--include-border-title", str(BOARD_PATH)],
        check=True,
    )


def export_gerbers():
    shutil.rmtree(GERBER_DIR, ignore_errors=True)
    GERBER_DIR.mkdir()
    subprocess.run(
        [kicad_cli(), "pcb", "export", "gerbers", "--output", str(GERBER_DIR),
         "--layers", "F.Cu,B.Cu,F.Mask,B.Mask,F.SilkS,B.SilkS,Edge.Cuts",
         "--subtract-soldermask", str(BOARD_PATH)],
        check=True,
    )
    subprocess.run(
        [kicad_cli(), "pcb", "export", "drill", "--output", str(GERBER_DIR), "--format", "excellon",
         "--excellon-separate-th", "--generate-map", "--map-format", "gerberx2", str(BOARD_PATH)],
        check=True,
    )
    GERBER_ZIP.unlink(missing_ok=True)
    shutil.make_archive(str(GERBER_ZIP.with_suffix("")), "zip", GERBER_DIR)
    shutil.rmtree(GERBER_DIR)


if __name__ == "__main__":
    write_project()
    build_board()
    run_drc()
    render_previews()
    export_gerbers()

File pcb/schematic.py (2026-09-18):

"""Generate the KiCad schematic from the net model in design.py.

Symbols, wire routes, and labels use explicit coordinates on the 1.27 mm grid.
The script writes hcp.kicad_sch beside the generator, runs KiCad ERC, exports
the netlist, checks it against EXPECTED_CONNECTIONS, and renders the PDF.
"""
import json
import re
import shutil
import subprocess
import sys
import uuid
from pathlib import Path

from design import J1_PINS, connections, git_version, selected_variant

SOURCE_DIR = Path(__file__).parent
OUTPUT_DIR = SOURCE_DIR
VARIANT = selected_variant()
EXPECTED_CONNECTIONS = connections(VARIANT)
PROJECT_NAME = f"hcp-{VARIANT}"
SCHEMATIC_PATH = OUTPUT_DIR / f"{PROJECT_NAME}.kicad_sch"
NETLIST_PATH = OUTPUT_DIR / f"{PROJECT_NAME}.net"
PDF_PATH = OUTPUT_DIR / f"{PROJECT_NAME}-schematic.pdf"
ERC_PATH = OUTPUT_DIR / f"{PROJECT_NAME}-erc.json"
GND_NET = "HCP_GND"

# Each part: symbol body half width, pins as (number, name, electrical type, side, dy).
# dy is the schematic offset of the pin below the symbol origin, on the 1.27 mm grid.
# Sides only matter for the drawing; the footprints define the real pin positions.
PARTS = {
    "J1": {
        "value": "HCP2 6P6C",
        "footprint": "HCP:RJ12_Amphenol_54601-x06_Horizontal",
        "at": (40.64, 88.9),
        "half_width": 10.16,
        # The signals keep their places in the drawing and only the contact numbers move
        # between the variants, so the numbers come from the net model.
        "pins": tuple(
            (int(J1_PINS[VARIANT][net_name][index].split(".")[1]), label, kind, "right", dy)
            for net_name, index, label, kind, dy in (
                ("HCP_25V", 1, "+25V", "passive", -6.35),
                ("HCP_25V", 0, "+25V", "power_out", -3.81),
                ("HCP_A_PLUS", 0, "A+", "passive", -1.27),
                ("HCP_B_MINUS", 0, "B-", "passive", 1.27),
                ("HCP_GND", 1, "GND", "passive", 3.81),
                ("HCP_GND", 0, "GND", "power_out", 6.35),
            )
        ),
    },
    "PS1": {
        "value": "LM2596 HW-411, 5.0 V",
        "footprint": "HCP:LM2596_HW-411",
        "at": (111.76, 63.5),
        "half_width": 10.16,
        "pins": (
            (1, "IN+", "power_in", "left", -2.54),
            (2, "IN-", "passive", "left", 2.54),
            (3, "OUT+", "power_out", "right", -2.54),
            (4, "OUT-", "passive", "right", 2.54),
        ),
    },
    "JP1": {
        "value": "BUS_PWR",
        "footprint": "HCP:PinHeader_1x02_P2.54mm_Vertical",
        "at": (160.02, 60.96),
        "half_width": 5.08,
        "pins": (
            (1, "1", "passive", "left", 0),
            (2, "2", "power_out", "right", 0),
        ),
    },
    "U2": {
        "value": "Isolated RS485, auto direction, 120R",
        "footprint": "HCP:RS485_Isolated_34x18",
        "at": (111.76, 114.3),
        "half_width": 10.16,
        "pins": (
            (5, "A+", "bidirectional", "left", -5.08),
            (6, "B+", "bidirectional", "left", 0),
            (7, "EARTH/NC", "passive", "left", 5.08),
            (1, "VIN", "power_in", "right", -3.81),
            (2, "TX (RO)", "output", "right", -1.27),
            (3, "RX (DI)", "input", "right", 1.27),
            (4, "GND", "power_in", "right", 3.81),
        ),
    },
    "U1": {
        "value": "ESP32-C3 Super Mini",
        "footprint": "HCP:ESP32-C3_SuperMini",
        "at": (210.82, 104.14),
        "half_width": 12.7,
        "pins": (
            (1, "5V", "power_in", "left", -8.89),
            (5, "3V3", "power_out", "left", -6.35),
            (16, "GPIO21/U0TXD", "input", "left", -1.27),
            (14, "GPIO20/U0RXD", "output", "left", 1.27),
            (3, "GND", "power_in", "left", 6.35),
            (7, "GPIO4", "bidirectional", "right", -8.89),
            (9, "GPIO3", "bidirectional", "right", -6.35),
            (11, "GPIO2", "bidirectional", "right", -3.81),
            (13, "GPIO1", "bidirectional", "right", -1.27),
            (15, "GPIO0", "bidirectional", "right", 1.27),
            (2, "GPIO5", "bidirectional", "right", 3.81),
            (4, "GPIO6", "bidirectional", "right", 6.35),
            (6, "GPIO7", "bidirectional", "right", 8.89),
            (8, "GPIO8/LED", "bidirectional", "right", 11.43),
            (10, "GPIO9/BOOT", "bidirectional", "right", 13.97),
            (12, "GPIO10", "bidirectional", "right", 16.51),
        ),
    },
}
PIN_LENGTH = 2.54

# Wires as point lists. Every net pin must be the first or last point of some wire.
WIRES = {
    "HCP_25V": (
        ((53.34, 85.09), (60.96, 85.09), (60.96, 60.96), (99.06, 60.96)),
        ((53.34, 82.55), (60.96, 82.55)),
    ),
    GND_NET: (
        ((53.34, 92.71), (58.42, 92.71), (58.42, 101.6)),
        ((53.34, 95.25), (58.42, 95.25)),
        ((99.06, 66.04), (93.98, 66.04), (93.98, 71.12)),
        ((124.46, 66.04), (129.54, 66.04), (129.54, 71.12)),
        ((124.46, 118.11), (129.54, 118.11), (129.54, 123.19)),
        ((195.58, 110.49), (190.5, 110.49), (190.5, 115.57)),
    ),
    "HCP_A_PLUS": (((53.34, 87.63), (66.04, 87.63), (66.04, 109.22), (99.06, 109.22)),),
    "HCP_B_MINUS": (((53.34, 90.17), (63.5, 90.17), (63.5, 114.3), (99.06, 114.3)),),
    "BUCK_5V": (((124.46, 60.96), (152.4, 60.96)),),
    "ESP_5V": (((167.64, 60.96), (185.42, 60.96), (185.42, 95.25), (195.58, 95.25)),),
    "ESP_3V3": (((195.58, 97.79), (180.34, 97.79), (180.34, 110.49), (124.46, 110.49)),),
    "UART_RX_GPIO21": (((195.58, 102.87), (182.88, 102.87), (182.88, 113.03), (124.46, 113.03)),),
    "UART_TX_GPIO20": (((195.58, 105.41), (187.96, 105.41), (187.96, 115.57), (124.46, 115.57)),),
}
# Ground symbols sit at the open end of the GND wires.
GND_SYMBOLS = ((58.42, 101.6), (93.98, 71.12), (129.54, 71.12), (129.54, 123.19), (190.5, 115.57))
# (net, x, y, rotation); the anchor must lie on a wire of that net.
LABELS = (
    ("HCP_25V", 76.2, 60.96, 0),
    ("HCP_A_PLUS", 76.2, 109.22, 0),
    ("HCP_B_MINUS", 76.2, 114.3, 0),
    ("BUCK_5V", 134.62, 60.96, 0),
    ("ESP_5V", 185.42, 78.74, 90),
    ("ESP_3V3", 152.4, 110.49, 0),
    ("UART_RX_GPIO21", 152.4, 113.03, 0),
    ("UART_TX_GPIO20", 152.4, 115.57, 0),
)
NOTES = (
    (f"HCP2 bus, 6P6C. {'Contact numbering per ESPHome HCP documentation; needs a reversed cable.' if VARIANT == 'cross' else 'Mirrored against the ESPHome HCP documentation; needs a straight cable.'}", 25.4, 128.27),
    ("Adjust PS1 to 5.0 V before connecting U1. Open JP1 whenever USB is plugged into U1.", 99.06, 45.72),
    ("U2 is powered from 3V3 so its TX output stays at ESP32 logic level.", 99.06, 132.08),
    ("U2 pin names are from the module's own view: TX drives the ESP32, RX is driven by it.", 99.06, 135.89),
)


def object_uuid(name):
    return str(uuid.uuid5(uuid.NAMESPACE_URL, f"hoermann-sch:{name}"))


ROOT_UUID = object_uuid("root")
FONT = "(effects (font (size 1.27 1.27)))"


def num(value):
    return f"{round(value, 2):g}"
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

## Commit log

2026-09-05 Initial hardware documentation and schematic
    [hoermann-hcp-adapter.kicad_sch]
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2026-09-05 Draw visible schematic connections
    [hoermann-hcp-adapter.kicad_sch]
2026-09-05 Arrange schematic around ESP32
    [hoermann-hcp-adapter.kicad_sch]
2026-09-05 Add provisional routed PCB
    [hoermann-hcp-adapter.kicad_pcb, hoermann-hcp-adapter.kicad_sch]
2026-09-05 Compact PCB layout with real module footprints
    Shrink the board to 63 x 42 mm, put the RJ12 jack at the edge and
    replace the placeholder footprints with a project library: KiCad's
    Amphenol 54601 footprint for the 95001-type jack, and LM2596 HW-411,
    isolated RS485 and ESP32-C3 Super Mini footprints measured from vendor
    material. Mounting uses the LM2596 module holes plus one hole under the
    ESP32. pcb.py now instantiates library footprints, checks routes against
    pad positions and runs DRC; the schematic assigns the same footprints.
    [hoermann-hcp-adapter.kicad_pcb, hoermann-hcp-adapter.kicad_sch]
2026-09-05 Loosen PCB spacing to 65 x 44.5 mm
    About 2 mm between module outlines and 1.5 mm to the board edge.
    [hoermann-hcp-adapter.kicad_pcb]
2026-09-05 Add bottom render, layer PDF and silkscreen labels
    JP1 gets a "DISCONNECT FOR USB" warning, the back side carries the
    project name, version and copyright.
    [hoermann-hcp-adapter.kicad_pcb]
2026-09-05 Move KiCad sources to hardware/pcb with generated/ output
    Sources (SKiDL circuit, PCB generator, footprints, symbols) stay in
    hardware/pcb; everything the scripts write, including the KiCad project
    and fp-lib-table, goes to hardware/pcb/generated. Renders are named
    -top.png and -bottom.png, the schematic PDF -schematic.pdf.
    [hoermann-hcp-adapter.kicad_pcb, hoermann-hcp-adapter.kicad_sch]
2026-09-05 Put the ESP32 USB port at the board edge
    U1 is rotated so its USB end sits flush with the right edge and stays
    usable when mounted. The antenna now points towards the RS485 module.
    [hoermann-hcp-adapter.kicad_pcb]
2026-09-05 Generate the schematic directly as KiCad file, centre the PCB plot
    schematic.py replaces the SKiDL flow: symbols with named pins, routed
    wires, net labels and ground symbols are written straight to .kicad_sch,
    then kicad-cli runs ERC, exports the netlist (checked against design.py)
    and renders the PDF. SKiDL and the vendored symbol library are gone.
    The PCB now sits centred on the A4 sheet of the layer PDF.
    [hoermann-hcp-adapter.kicad_pcb, hoermann-hcp-adapter.kicad_sch]
2026-09-05 Stamp outputs with the git hash and export gerbers
    Silkscreen and schematic title block carry the short HEAD hash, with a
    -dirty suffix when sources outside generated/ have uncommitted changes.
    pcb.py also exports gerbers plus excellon drill files into a zip.
    [design.py, pcb.py, schematic.py]
2026-09-05 Regenerate outputs
    [hoermann-hcp-adapter.kicad_pcb, hoermann-hcp-adapter.kicad_sch]
2026-09-05 Fix dirty check pathspec
    [design.py]
2026-09-05 Drop the J1 pin order warning
    The Amphenol footprint follows the standard modular jack contact
    numbering, so the order cannot be mirrored.
2026-09-05 Use a 95001-family footprint for the HCP jack
    The 95001 jacks have 1.02 mm staggered pins in rows 8.3 and 10.84 mm
    behind the board edge and 2.4 mm pegs spaced like the body, which does
    not match the Amphenol 54601 footprint. RJ12_95001_6P6C is built from
    the vendor drawings (6P6C sibling and the 8P8C variant with pin numbers).
    J1 sits flush with the top edge and the surrounding routing is redone.
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2026-09-05 Add four M3 enclosure holes
    Holes sit in the free spots: below J1, beside JP1, between U2 and U1,
    and under the socketed ESP32. B- and BUCK_5V are rerouted around them.
    Footprint item uuids are made unique per placement.
2026-09-06 Add a printed enclosure for the carrier board
    build123d model after the ventilsteuerung cases in the cad repo: tray with
    M3 heat-set standoffs on H1..H4, screwed lid with a hex vent pattern, one
    opening for the 6P6C plug at J1. Module heights are vendor figures, marked
    UNGEPRÜFT.
    [bottom.stl, top.stl]
2026-09-06 Move the enclosure under hardware/, derive the board mockup from pcb.py
    Board size, hole pattern and module placement now come straight from
    pcb.PLACEMENT and the F.Fab outlines in HCP.pretty; only heights and the
    coarse module features stay hand-set. Solder joints under the board are
    modelled from the pad sizes, which showed that H2 cannot carry a standoff
    (PS1 pad 3 sits 3.3 mm away) and H3 only a Ø7.2 one. H2 is dropped in
    favour of a ledge along the +Y wall; both go to TODO as board changes.
    [bottom.stl]
2026-09-06 TODO: own section for the enclosure, mounting holes under the board blockers
2026-09-06 Enclosure: 2.4 mm walls, 2.8 mm lid, 4 mm headroom
    [bottom.stl, top.stl]
2026-09-06 Enclosure: ledge runs into the corner columns, preview.stl/.3mf of the assembly
    [bottom.stl, preview.3mf, preview.stl]
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2026-09-06 Enclosure: colour the 3MF preview per solid
    Mesher writes the solids of a Part one by one and reads colour and name from
    each solid, so the Part-level attributes never reached the file.
    [preview.3mf]
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2026-09-06 Shorten generated file prefix to hcp
    [hcp.kicad_pcb, hcp.kicad_sch]
2026-09-06 Stack the legend under J1 and move its reference into the footprint
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2026-09-06 Use measured LM2596 module dimensions
    Board 43.4 x 21.2 mm and corner pads 39.4 x 17.5 mm measured on the
    delivered module. U1 and U2 confirmed against the parts.
2026-09-06 TODO: enclosure items after the measured LM2596, regenerate the previews
    [preview.3mf, preview.stl]
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2026-09-06 Enclosure: follow the Amphenol J1 footprint and the three-hole board
    Module outlines come from the bounding box of the F.Fab drawing, which
    also covers KiCad library footprints drawn with lines. J1 is 13.2 x 18 mm
    with the latch towards the board, so the plug opening now reaches 3 mm
    below the board for the latch lever and the ledge is interrupted there.
    All three holes clear the solder joints for Ø8 standoffs, so standoff_wall
    is back at 2.0.
    [bottom.stl, preview.3mf, preview.stl]
2026-09-06 Restructure hardware project and translate documentation
    [bottom.stl, hcp.kicad_pcb, hcp.kicad_sch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]
2026-09-06 Flatten project outputs and refine README
    [hcp.kicad_pcb, hcp.kicad_sch]
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2026-09-17 Add the ESPHome configuration
    hcp.yaml exposes the cover, opener light, vent and half-open buttons, and the
    bus connection sensor. Wi-Fi provisioning goes through improv_serial over USB,
    compiled secrets, or the fallback access point with captive portal, the only
    path that works with the enclosure closed. Both reboot timeouts are disabled
    because a restart leaves the opener unresponsive until it is power-cycled.
    Validated with esphome config.
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2026-09-18 Correct the UART pin roles against the RS485 module
    The module names its TTL pads from its own point of view, so the pad marked
    TX is the receiver output that drives the MCU. Wiring the ESP32 transmitter
    to it left the RS485 driver permanently off, which is why the adapter never
    registered on the bus.
    The copper is unaffected, only the net names, the symbol pin directions and
    the ESPHome pin assignment change. Confirmed on the assembled board: A/B move
    from the 185 mV idle bias to 1.62 V under transmit load, and the opener now
    polls the adapter continuously.
    [hcp.kicad_pcb, hcp.kicad_sch]
2026-09-18 Document the reversed cable and how to debug a silent bus
    The opener's jack is mirrored against the pinout J1 follows, so a straight-
    through cable puts +25 V on the adapter's ground. That cost a reverse-polarity
    event during bring-up, survived only because the opener limits accessory
    current to 350 mA.
    The troubleshooting section collects the bench measurements that found the
    pin-role bug, because the bus itself is unusable for debugging: it carries
    power only during a scan and drops it again within seconds.
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2026-09-18 Generate a straight-cable variant of the carrier PCB
    The opener's 6P6C jack is mirrored against the pinout in the ESPHome
    documentation that J1 follows, so the board built here needs a reversed cable.
    That is the single most dangerous detail of the project, because the wrong
    cable puts +25 V on the adapter's ground.
    Both boards are now generated from the same sources and differ only in the
    J1 net map and the routes that touch it. Each one prints the cable it wants on
    its silkscreen, X for reversed and II for straight.
    The straight variant needs one extra via: supply and ground swap ends of the
    contact row, which leaves A+ on the far side of the ground trace.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
    [hcp.kicad_pcb, hcp.kicad_sch]
2026-09-18 Regenerate both board variants
    [hcp-cross.kicad_pcb, hcp-cross.kicad_sch, hcp-straight.kicad_pcb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]
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
